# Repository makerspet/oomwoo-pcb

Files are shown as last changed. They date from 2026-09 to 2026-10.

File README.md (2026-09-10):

<div align="center">

# OOMWOO I/O Board

*Open-source robot vacuum you build yourself.*

Raspberry Pi CM4/CM5 socket · STM32G473 MCU · Motor drivers · Sensors · 2x MIPI cameras · 4S charging · KiCad





</div>

Part of [OOMWOO open-source robot vacuum](https://github.com/makerspet/oomwoo) project.

oomwoo_main_pcb_placement

Get [MCU firmware](https://github.com/makerspet/oomwoo-io-firmware/).

## Architecture notes

Consumer vacuums typically split compute into CPU and MCU. The MCU ([real examples](https://robotinfo.dev/)) controls
- all motors - driving wheels, suction fan, side brushes, mop motors, mop lift servos, pump and so on
- all sensors except below - IR cliff, IR side proximity, IR docking, wheel drop, bumper (IR or micro-switches), motor encoders, ultrasonic carpet sensor
- all push buttons
- 2D LiDAR motor RPM
- power - battery charging, motors power on/off
- all safety sensors - overcurrent for all motors (cheap vacuums ignore overcurrent sensing)

I/O board also provides audio encoders/decoders, amp, speaker (connector), mics (if any).

CPU receives
- 2D LiDAR data over serial port
- IMU (sometimes IMU gets forwarded via MCU) over SPI/I2C
- cameras (2x MIPI for visual obstacle avoidance)

MCU (and CPU) are usually always active. This allows the user to start cleaning at any time (especially via app remotely). Exceptions:
- no power (battery dead and no dock power)
- user explicitly shut down the vacuum by long-pressing the power button

The MCU's overarching constraint is to ensure robot safety. This is necessary to pass CE mark tests. Here is how MCU ensures safety:
- MCU firmware uses FreeRTOS or similar, static memory allocation, watchdog, guaranteed reaction time
- MCU acts as watchdog for CPU, resets CPU if CPU becomes unresponsive
- MCU connects to CPU over serial using a custom serial protocol ([concrete example](https://github.com/codetiger/VacuumRobot)). No micro-ROS to reduce dependencies, prevent bugs from updated 3rd party libraries slipping into safety-critical MCU firmware.
- MCU shuts down some (or all) motors when MCU detects overcurrent (brush stuck)
- MCU shuts down all motors (including power to all motors) when CPU becomes unresponsive (to prevent CPU sending garbage commands to MCU)
- MCU monitors battery charging, shuts it down when needed (battery too hot)
- MCU stops driving wheel motors when bumper sensors activate
- MCU tests motors, sensors
- MCU does not depend on CPU
- MCU toggles watchdog GPIO; otherwise an external-to-MCU circuit shuts down motor power

Consumer vacuums place CPU and MCU on the same PCB board. Since OOMWOO has to be hackable, it seems best to separate I/O from the compute. Therefore, this I/O board needs to have
- MCU and programming header
  - likely STM32G070RBT6 because it has 56 GPIOs, 16 ADC channels, costs $1 at JLCPCB, has LQFP package for easy PCBA - a rare combination
  - see tentative [I/O board spec](https://github.com/makerspet/oomwoo-io-board/blob/main/docs/SPEC.md)
- all vacuum motor drivers (with connectors), driven by the MCU
  - cliff, side proximity, docking, bumper, carpet, water tank full/empty, dust bin present, motor overcurrent, motor encoders
- MCU connected to all sensors (except those handled by CPU like LiDAR serial, MIPI cameras I/O, IMU); sensor connectors
- control circuit for 2D LiDAR's motor (controlled by MCU)
- battery charging, power management (motors power on/off, charging on/off, power shut down), power for CPU compute module (see below)
- push buttons (home, power, etc.) and UI LEDs
- dock connector (dock power, sense dock present)
- USB power for charging; USB for serial shell, etc.
- audio encoder/decoder, audio amp, mics (if any)
- SD card for hacking, cheap large storage
- connect IMU FSYNC to MCU to synchronize MCU timestamps with IMU data streaming to CPU

Consumer vacuums usually don't have a CPU fan/heatsink because the vacuum's suction fan can (indirectly) cool the CPU/MCU PCB. Therefore, no CPU fan on this I/O board.

As far as compute - currently it seems best to use a Raspberry Pi CM4/CM5 compute module. Why?
- CM4/CM5 modules cost a bit less than a full Raspberry Pi 4/5
- CM4/CM5 have lower profile/height vs a full Raspberry Pi 4/5, important to keep vacuum cleaner slim
- there are plenty of 3rd party compute modules pin-compatible with CM4/CM5, making the compute swappable, hackable
  - 3rd party compute modules with NPUs are especially interesting because we need NPU for real-time camera-based obstacle detection

Compute module headers should expose
- 2x MIPI camera I/O
- 1x serial for CPU-MCU comms
- 1x serial for CPU-LiDAR comms
- 1x SPI (or I2C) for CPU-IMU comms
- audio (digital?) I/O
- power from I/O board to CM
- a few TBD GPIOs
  - MCU GPIO to reset CPU

This board should be designed using an open-source PCB tool (KiCad seems like a good choice).

## License

[Apache License 2.0](LICENSE).

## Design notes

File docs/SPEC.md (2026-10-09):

# OOMWOO I/O Board spec (work in progress)

See [vacuum BOM](https://github.com/makerspet/oomwoo/blob/main/BOM.md) for details.

## Reverse engineering data

Drive, brush and fan motors draw power directly from the 4S battery (not via a DC-DC converter). The battery is 4*3.6V=14.4V nominal, 4*2.9V=11.6V discharged and 4*4.2V=16.8V fully charged.

### DC Motors

<table>
  <tr><th>Part</th><th>Voltage</th><th>No load</th><th>Stall</th><th>Notes</th></tr>

  <tr>
    <td rowspan="3">Drive wheel</td><td>16.8V</td><td>0.12A</td><td>2A</td>
    <td rowspan="3">JST ZH 1.5mm 7-pin housing; RS-360-SH-15250 motor;
      pin 1 MOT+, 2 MOT-, 3 Hall GND (brown), 4 Hall signal out (blue, open collector), 5 Hall VCC (3.3-5V, orange), 6 COM wheel drop switch, 7 ON wheel drop switch;
      fits Roborock S4 Max, S45 Max, S5 Max, S50 Max, S55 Max, S6 MaxV, S6 Pure, S65 Pure, S65 MaxV, S7, S7 Pro, S7 MaxV, S7 Max Ultra, S70, S75, E4, E45, E5, E50, E55, G10, T7, T7S, Q5, Q7, Q7 Max, and Q Revo;
      purchased <a href="https://www.aliexpress.us/item/3256811615892849.html">here</a>; power supply current limit headroom ~1A;
      the wheel assembly appears to be identical to <a href="https://github.com/makerspet/oomwoo/tree/main/contributions/part-specs/IKsares/drive-wheel">this one</a> available
      <a href="https://www.aliexpress.us/item/3256807172774304.html">here</a> that uses GM-RS360-16248 motor with stall current possibly reaching ~3A.
    </td>
  </tr>
  <tr><td>14.4V</td><td>0.12A</td><td>1.7A</td></tr>
  <tr><td>12V</td><td></td><td></td></tr>

  <tr>
    <td rowspan="3">Main brush</td><td></td><td></td><td></td>
    <td rowspan="3">Roborock S50 S51 S55 XIAOWA C10</td>
  </tr>
  <tr><td>16.8V</td><td>0.27A</td><td>7A</td></tr>
  <tr><td></td><td></td><td></td></tr>

  <tr>
    <td rowspan="3">Side brush FlexiArm</td><td></td><td></td><td></td>
    <td rowspan="3">RC500-KW/14440/DV motor; JST ZH 1.25mm 5-pin housing, 14.4V motor nominal;
      pin 1 MOT-, 2 MOT+, 3 IR output? (Arm folded in fully -> sensor blocked), 4 IR GND? 5 IR VDD?
      fits Roborock Qrevo Master, Qrevo Slim, S8 Max V Ultra</td>
  </tr>
  <tr><td>16.8V</td><td>0.07A</td><td>1.7A</td></tr>
  <tr><td></td><td></td><td></td></tr>

  <tr>
    <td rowspan="3">Side brush fixed</td><td></td><td></td><td></td>
    <td rowspan="3">RC500-KW/14440/DV motor; fits Roborock Robot Vacuum S50 S51 S52 S55 S502-00/01/02/03** S552-00 S60 S61 S65 S5 Max S6 Pure MAX S7 S70 S75</td>
  </tr>
  <tr><td>16.8V</td><td>0.07A</td><td>1.7A</td></tr>
  <tr><td></td><td></td><td></td></tr>

  <tr>
    <td rowspan="3">Mop rotary fixed</td><td>16.8V</td><td>0.15A</td><td>5.3A</td>
    <td rowspan="3">JST PH 2.0 4-pin housing, RS-385PH-2466 motor; pin 1 VCC fixed, 2 GND fixed, 3 GND FlexiArm, 4 VCC FlexiArm;
    fits Roborock Qrevo Master, Qrevo Slim, S8 Max V Ultra, G20S, V20, P10S Pro</td>
  </tr>
  <tr><td>14.4V</td><td>0.16A</td><td>4.3A</td></tr>
  <tr><td>11.6V</td><td>0.15A</td><td>3.7A</td></tr>

  <tr>
    <td rowspan="3">Mop rotary FlexiArm</td><td>16.8V</td><td>0.2A</td><td>5A</td>
    <td rowspan="3">JST PH 2.0 4-pin housing, RS-385PH-2466 motor; pin 1 VCC fixed, 2 GND fixed, 3 GND FlexiArm, 4 VCC FlexiArm;
    arm actuator likely JST GH 1.25; pin 1 black (ground?), 2 red (power?);
    fits Roborock Qrevo Master, Qrevo Slim, S8 Max V Ultra, G20S, V20, P10S Pro</td>
  </tr>
  <tr><td>14.4V</td><td>0.17A</td><td>4.3A</td></tr>
  <tr><td>11.6V</td><td>0.16A</td><td>3.6A</td></tr>

  <tr>
    <td>Water mini-pump</td><td>5V</td><td>55mA</td><td></td>
    <td><a href="https://www.tcstec.com">TCS Precision Technology<a>JSB1523025 peristaltic, 5V nominal (loud); JST ZH 2-pin housing; pin 1 MOT+, 2 MOT-</td>
  </tr>

  <tr>
    <td>Water mini-pump</td><td>5V</td><td>60mA</td><td></td>
    <td><a href="https://www.dyxminipump.com">ShenZhen Deyuxin Technology</a>DSB030-C peristaltic, 5V nominal (quiet); JST PH 2.0 2-pin housing; pin 1 MOT+, 2 MOT-</td>
  </tr>

  <tr>
    <td>Water mini-pump</td><td>5V</td><td>87mA</td><td></td>
    <td><a href="https://www.dgjbf.com">Dongguan Jingbofang Precision Electronics<a>JSB030-5A peristaltic, 5V nominal (loud); no connector</td>
  </tr>

  <tr>
    <td>Water mini-pump</td><td>5V</td><td>110mA</td><td></td>
    <td><a href="www.yyjiayin.com">Jiayin</a> JYPDM-6B peristaltic, 5V nominal (quiet-ish); JST XH 2.54mm 2-pin; pin 1 MOT+, 2 MOT-</td>
  </tr>

  <tr>
    <td>Water mini-pump</td><td>5V</td><td>330mA</td><td></td>
    <td><a href="https://conjoinfluid.com/">Conjoin</a> CJWP12-AA05A peristaltic, 5V nominal (loud); likely JST GH 1.25mm housing; pin 1 blue (ground?), 2 red (power?)</td>
  </tr>

</table>

### BLDC Motors

<table>
  <tr><th>Part</th><th>Voltage</th><th>Unobstructed</th><th>Fully Obstructed</th><th>Notes</th></tr>

  <tr>
    <td rowspan="3">Fan MSD-G v1</td><td>16.8V</td><td>3.65A</td><td>6A</td>
    <td rowspan="3">LHE MX3.0 4-pin (2x2) 3.0mm with latch header (aka Molex Micro-Fit 3.0); pin 1 VCC, 2 GND, 3 FG (open collector), 4 PWM (low off);
    fits Dreame X50 Ultra (20 kPa), X50 Master (20kPa)</td>
  </tr>
  <tr><td>14.4V</td><td>4.2A</td><td></td></tr>
  <tr><td>12V</td><td>5.25A</td><td></td></tr>

  <tr>
    <td rowspan="3">Fan BL27302101</td><td>16.8V</td><td>1.8A</td><td>1.8A</td>
    <td rowspan="3">JST PA 2mm 6-pin shrouded header; pin 1 VCC, 2 VCC, 3 GND, 4 GND, 5 PWM (low off), 6 FG (open collector);
    fits Roborock Saros 20 (36 kPa); </td>
  </tr>
  <tr><td>14.4V</td><td>2.1A</td><td></td></tr>
  <tr><td>12V</td><td>2.5A</td><td></td></tr>

  <tr>
    <td rowspan="3">Fan BL24131616<sup>*</sup></td><td>16.8V</td><td>1.75A</td><td>1.75A</td>
    <td rowspan="3">JST PA 2mm 5-pin shrouded header; pin 1 ID (22k to GND), 2 FG (open collector), 3 PWM (low off), 4 GND, 5 VCC;
    fits Roborock G20S P10 Pro (7 kPa), P10s Pro (11 kPa), P20, G20S S8 MaxV (10 kPa), Xiaomi S40 OV81 (10 kPa)</td>
  </tr>
  <tr><td>14.4V</td><td>2.1A</td><td>2.1A</td></tr>
  <tr><td>12V</td><td>2.6A</td><td>2.6A</td></tr>

  <tr>
    <td rowspan="3">Fan 22N704V160<sup>*</sup></td><td>16.8V</td><td>1.75A</td><td>3.25A</td>
    <td rowspan="3">JST PA 2mm 5-pin shrouded header; pin 1 ID (5 Ohm to GND), 2 FG (open collector), 3 PWM (low off), 4 GND, 5 VCC;
    fits Roborock G20S P10 Pro (7 kPa), P10s Pro (11 kPa), P20, G20S S8 MaxV (10 kPa), Xiaomi S40 OV81 (10 kPa)</td>
  </tr>
  <tr><td>14.4V</td><td>2.05A</td><td>2.7A</td></tr>
  <tr><td>12V</td><td>2.5A</td><td>2A</td></tr>

  <tr>
    <td rowspan="3">Fan 20N704R990F aka 20N704R980</td><td></td><td></td><td></td>
    <td rowspan="3">JST PH 2.0mm 4-pin shrouded header; pin 1 FG (open collector), 2 PWM (low off), 3 GND, 4 VCC; 20N <a href="https://www.nidec.com/en/product/search/category/B101/M102/S100/NCJ-20N-Type-4/">motor spec</a>
      ~5.1-6 kPa, fits Roborock S7 (2.5 kPa), S7 Pro (5.1 kPa), S7 MaxV (5.1 kPa), S75 MaxV (5.1 kPa), S8 (6 kPa), S8 Plus (6 kPa), S8 Pro Ultra (6 kPa), S8 MaxV Ultra (8 kPa), G20 (6 kPa), Q7 Max (4.2 kPa), Q7 Max Plus (4.2 kPa)</td>
  </tr>
  <tr><td></td><td></td><td></td></tr>
  <tr><td></td><td></td><td></td></tr>

  <tr>
    <td rowspan="3">Fan MSD-C-3</td><td></td><td></td><td></td>
    <td rowspan="3">JST PH 2.0mm 4-pin shrouded header; pin 1 FG (open collector), 2 PWM (low off), 3 GND, 4 VCC;
      fits Dreame L10s Prime (4 kPa), L10s Prime Ultra (5.3 kPa v1), L10s Prime Pro, D10s Plus (5 kPa), X10+ (4 kPa), X20+ (6 kPa)</td>
  </tr>
  <tr><td></td><td></td><td></td></tr>
  <tr><td></td><td></td><td></td></tr>

  <tr>
    <td rowspan="3">Fan MSD-D</td><td></td><td></td><td></td>
    <td rowspan="3">JST PH 2.0mm 4-pin shrouded header; pin 1 FG (open collector), 2 PWM (low off), 3 GND, 4 VCC;
      fits Dreame L20 (7 kPa), L30 Ultra (7.3 kPa), S10 (5.3 kPa), S10 Plus (7 kPa)</td>
  </tr>
  <tr><td></td><td></td><td></td></tr>
  <tr><td></td><td></td><td></td></tr>

  <tr>
    <td rowspan="3">Fan 20N709U020</td><td></td><td></td><td></td>
    <td rowspan="3">JST PH 2.0mm 4-pin shrouded header; pin 1 FG (open collector), 2 PWM (low off), 3 GND, 4 VCC;
      fits Dreame L10s Ultra (5.3 kPa), L10s Pro (5.3 kPa), L10 Ultra (5.3 kPa), D10s Pro (5 kPa); Xiaomi X20+ (6 kPa), C102 B101CN, X10+ (4 kPa), S10 Plus (4 kPa)
    </td>
  </tr>
  <tr><td></td><td></td><td></td></tr>
  <tr><td></td><td></td><td></td></tr>

  <tr>
    <td rowspan="3">Fan BL24131607</td><td></td><td></td><td></td>
    <td rowspan="3">JST PH 2.0mm 5-pin shrouded header; pin 1 ID (20k to GND), 2 FG (open collector), 3 PWM (low off), 4 GND, 5 VCC;
      fits Roborock P10 Pro (7 kPa), Qrevo Maxv (7 kPa), P10S (7 kPa), Qrevo S (7 kPa), Qrevo Pro (7 kPa)</td>
  </tr>
  <tr><td>15V</td><td>1.7A</td><td>2.7A</td></tr>
  <tr><td></td><td></td><td></td></tr>

</table>

### Sensors, Battery

<table>
  <tr><th>Part</th><th>Voltage</th><th>Notes</th></tr>

  <tr>
    <td>Cliff sensors</td><td></td>
    <td>JST PHDR-16VS 2.0mm 8x2 housing, mates JST S16B-PHDSS, JST B16B-PADSS; fits iRobot Roomba 500 600 700 800 528 552 564 595 560 570 610 615 620 625 630 650</td>
  </tr>

  <tr>
    <td>Battery</td><td></td>
    <td>4S2P 14.4V nominal <a href="https://images.thdstatic.com/catalog/pdfImages/55/55d2f7f6-2ed9-44ed-ab4e-fb20d231c897.pdf">BRR-2P4S-5200FL battery</a> or similar;
    4-pin 3mm pitch with latch male LHE MX3.0 (C3001-H04), Molex Micro-Fit 3.0;
    pin 4 BAT+, 3 NTC (10.7K), 2 ID (0.62M to ground), 1 GND</td>
  </tr>

  <tr>
    <td>Carpet sensor</td><td>14.4V (VUS boost rail)</td>
    <td>290KHz piezo ultrasonic, <a href="https://htwsensor.en.made-in-china.com/product/HfMYgjwoZxVh/China-300kHz-Carpet-Material-Recognition-Sensor-for-Robotic-Vacuum-Cleaner-Ultraosinc-Sensor.html">likely this one</a>,
      JST ZH 2-pin housing; <a href="https://makerspet.com/blog/how-to-source-bom-for-oomwoo-open-source-vacuum-robot/#carpet-sensor">sourcing notes</a>
      pin 1 white, 2 black (driven by AC, polarity doesn't matter?)
    </td>
  </tr>

</table>

All components tested with Agilent 6653A unless mentioned otherwise. The current limit was set high enough to not be triggered.

<sup>*</sup> Appear to be interchangeable

Mop lift TBD

Mop arm actuator - Roborock FlexiArm; later replace with own design

## Compute + Camera

- Camera (changed Oct 2026): the camera moves off the Compute Module to the STM32 - one parallel-interface (DVP) RGB module, so it also works when an old smartphone is the compute. See [Front sensors module board](#front-sensors-module-board). **Open:** keep the 15-pin MIPI connectors as a Pi-only option, or drop them? The schematic's MIPI-CAMERA sheet predates this change.
- internal USB 2.0 header (JST GH 4-pin, 0.5 A polyfuse, USBLC6 ESD) for the optional mic-array board or `rpiboot`; see [USB, UART allocation](#usb-uart-allocation)
- M.2 slot provisioned, PCIe lane routed, with its own 3.3 V buck (VCC3V3_M2, enabled by the CM via PCIE_PWR_EN) - to experiment with NPU accelerator(s) like Hailo
- SD card slot, powered through an RT9742 load switch (SD_PWR_ON)

Undecided TODO 
- USB-C 3.0+, CM5 only - to experiment with accelerator(s) like Coral TPU
- Keep the compute socket able to take an integrated-NPU module too (Radxa CM5) or premium-upgradeable (CM5 + M.2 Hailo).
- Flag it to the PCB contractor as a design item: M.2 E-key (WiFi) + an M.2 M-key/PCIe (NPU or NVMe), PCIe lane routing, and the thermal path for a few-watt accelerator in a suction-cooled enclosure

### Robot

Current schematic (2026-09):
- charging input is 24 V DC, from the dock contacts (CONTACT_CHGR) or a DC-005 barrel jack, into an SLM6900 buck charger configured for 4S (about 2.2-2.6 A). The battery NTC goes straight to the charger, so over-temperature cut-off is in hardware
- the system rails run from the battery (BAT-VCC), not from a power-path SYS rail
- USB-C is a 5 V *output* for the phone-as-compute option (AP64501 buck enabled by PWR_EN, through a TMI6240 current-limited switch), with D+/D- to the STM32 USB (PA11/PA12). **TODO:** CC1/CC2 are unconnected; a phone on a C-to-C cable will neither charge nor enumerate until CC is configured (Rp to charge, Rd for the phone-as-host data mode)
- the USB-C PD input and power-path charger below are the original plan, not in the current schematic

Original plan:
- the robot has 2 power inputs: USB-C and dock
  - robot receives 20-24V fixed DC from the dock
  - USB-C power use PD, request 20-24 V minimum (to step it down to 4S battery)
  - optional PPS
  - if a low-power USB-C 5V, 9V or 15V brick source is attached (no 20V/PPS), either charge slowly (optional) through a boost path or cleanly refuse and signal "insufficient charger" rather than misbehaving
- robot requires 65W minimum input (from the dock) with system power-path charger (a charger IC with a SYS rail)
  - support the vacuum charging and Raspberry Pi running simultaneously
  - assume Raspberry Pi is always on (to handle user access over Wi-Fi at any time)
  - Pi CM5 worst case ~15.6W
  - M.2
  - Healthy charge ~40 W (~0.5C into the 75 Wh pack)
  - ~65–70 W total
- cap charge at ~0.5C regardless of charging adapter power
- MCU reset drops everything to a safe state, so motors are off during reset, firmware upload and firmware crash
  - watchdog: see [Safety and power rails](#safety-and-power-rails)

### Dock

- the dock is powered from an external certified 24/25.2 V DC brick (~200–350 W)
  - use external brick for safety, the dock enclosure only ever sees 24 V DC
  - reuse a 25.2 V stick-vac motor for auto-empty, e.g. Dreame M10-E-4 25.2 V/310 W
- the dock has only 2 contacts: DOCK+ and GND
  - dock contacts feed a fixed 24V+ DC
  - the dock detects load/robot presence, energizes DOCK+ only when robot is detected (reliably, after a couple of seconds)
  - dock contacts are spring loaded, gold-coated pogo pins ≥4 A, placed rear-vertical, above water line
- ambient fan(s) for mop drying
  - no hot mop dry for now
- 2x water pumps: clean-feed + dirty-evacuate
  - diaphragm, 12–24 V
- dock PCB
  - ESP32 (WiFi + BLE + control)
  - Pump/fan drivers (brushed DC)
  - IR beacon LEDs + driver
  - robot/load presence-detect + charging contact energize FET
  - Level sensors (float/capacitive) clean-low, dirty-full
  - high-side FET for auto-empty blower
  - fuse, DC inlet, TVS
  - buck DC-DC 24V to 5V, 3.3V for ESP32, sensors

### IR receiver ICs

- required to 1) find dock without map (beacon), 2) communicate with the dock (bi-directional, ~1 kbit/s)
  - Maybe we'll use LiDAR for docking (simpler mechanical, PCB design). If that fails, 3) docking.
- use 38 kHz NEC protocol receivers (56 kHz parts are Vishay-only, expensive, barely stocked)
  - firmware: time-share IR transmissions
  - dock stops 
- TSOP38238 costs ~$0.56, relatively expensive; economical IC options, sorted by preference
  - Everlight IRM-H638T/TR2	C91447 SMD 5×4 $0.168 194k Deep stock, reputable.
  - Everlight IRM-3638T	C42421366 Through-hole $0.103 206k Side-looking, cheapest reputable through-hole; [datasheet](https://www.alldatasheet.com/datasheet-pdf/view/229626/EVERLIGHT/IRM-3638T.html).
  - Yongyu GRM-4033H4C6-ET2	C51901765	SMD	$0.118	2.7k	50 µA, 2.4–5.5 V. Best SMD challenger.
  - TONYU DY-IRM383T/LP-T-20	C46682928	Through-hole	$0.068	420	100 µA, 2.7–5.5 V. Cheapest real receiver, sunlight rejection not specified; [datasheet](https://file.aichiplink.com/static/lcsc/documents/2026-01-29/18c143340b0d5fc0ffdf5ff7098aaff5.pdf).
  - TONYU DY-IRMA385-T5-W1-F1	C7433009	SMD-3P	$0.110	2.1k	200 µA, ±35°. Narrower field of view.
  - Chau Light ZSIRM-Z1QN86	C5337492	SMD 5×4.2	$0.112	1.8k	400 µA, 45°.
  - TONYU DY-IRMA386/387	C6075467/68	Through-hole	$0.128	124/660	±60° wide field of view, low stock.
  - XINGLIGHT XL-IRM0038C-38X	C42400831	SMD 5×4.2	$0.133	137	150 µA, 75°, –40 °C to +85 °C. Stock too thin.
- Deciding factors - stock depth, sunlight rejection, SMD (cheaper to assemble), angle of view (wide for dock search, narrow for docking, comms), side-looking vs straight up orientation
  - current draw battery drain is not a factor

### Power path

Standard capability of power-path charger ICs - TI bq25 family and similar.

```
USB-C 20V ─► [PD sink] ─► [power-path charger] ─┬─► SYS rail ─► 14.4→5V buck ─► Pi (always-on)
                                                └─► charges 4S pack
Battery ────────────────────────────────────────┘ (supplements SYS if input insufficient)
```

- Docked: the Pi runs from the input via SYS; the battery charges from the surplus; once full, charge current → 0 and the Pi keeps running off input — no needless battery cycling while docked (also a longevity win).
- Undocked: SYS seamlessly falls back to the battery — the Pi never browns out during the handoff. This is exactly what makes "pause → return to charge → resume" and "app connects anytime" work cleanly.
- Input-limited: if only a weak brick is attached, the battery supplements SYS so the Pi stays up, and charge current backs off. Graceful degradation for free.

Details

1. 65 W = 20 V / 3.25 A → e-marked cable required. Above 3 A / 60 W, USB-C needs a 5 A e-marked cable. Unavoidable at 65 W (20 V is PD's max fixed voltage) — just document it. 65 W bricks ship with an e-marked cable anyway.
2. Dynamic power management (VIN/IIN-DPM): the charger must throttle charge current to keep total draw within the negotiated PD budget, prioritizing the Pi/SYS load. Standard on power-path chargers.
3. Cap charge current at ~0.5C (~2.6 A into the pack) for cell life, regardless of surplus — don't let a big brick fast-charge the cells.
4. Two DC inputs, one charger: the robot's own USB-C port and the dock contacts both present ~20 V DC → OR them into the charger's VBUS with priority/ideal-diode selection (both are the same voltage, so it's clean).
5. Dock side: dock has its own PD sink + 65 W brick, passes ~20 V to the contacts. At 20 V, 65 W ≈ 3.25 A over the contacts → size the pogo/spring contacts for ~4 A with margin.

Net spec

1. USB-C PD, 65 W minimum (20 V / 3.25 A), on both the robot port and the dock (each with its own PD sink); e-marked cable expected.
2. Power-path 4S charger with a SYS rail feeding the Pi's 5 V buck, so the Pi is always-on from input when docked and from battery when not, with seamless handoff and battery-supplement under load.
3. DPM + 0.5C charge-current cap; OR the two DC inputs into one VBUS; dock contacts rated ~4 A.

## How to drive carpet sensor

- 290KHz ultrasonic piezoelectric analog
- 14.4 V DC stabilized (VUS, MT3608 boost from 5 V; not the 4S battery directly)
  - DC voltage set by the MT3608 feedback divider: VUS = 0.6 V x (1 + R160/R159) = 0.6 x (1 + 232k/10k) ≈ 14.5 V
  - current consumption - calculate 300KHz driving 1300±20% pF per sensor spec
  - make it withstand shorts
- connect sensor analog I/O to MCU ADC input
- use STM32G473VCT6 internal op-amp as echo input (AC via a cap)
- clamp amplitude to 3.3V (back-to-back clamp diodes)
- add a series resistor to STM32 op-amp input (extra protection against 12V)
- (firmware) bias the MCU internal op-amp to Vref/2 using MCU internal DAC
- (firmware) configure ADC pre-amp gain, PGA mode (op-amp bandwidth is 10MHz)
- (firmware) configure op-amp to output signal to internal ADC channel
- drive sensor analog I/O with one low-side N-FET (Q18, AO3400) and a 330 Ω 1206 pull-up (R7011) from VUS, AC-coupled to the piezo through C18
  - the earlier P/N half-bridge was dropped: its high side turned off through a 100k pull-up, far too slow at 290 kHz, so both FETs would conduct every cycle (shoot-through)
  - one GPIO (LO) drives the gate through R60 (10 Ω); R7012 (100k) pulls the gate low so the FET is off while the MCU is in reset or being flashed
  - the freed HI GPIO now enables the motor rail (~VM-VBAT-EN)
- (firmware) drive the sensor in short bursts only: LO held high puts ~0.63 W into R7011
- (firmware) release LO (low), then measure using ADC, calculate return amplitude
- TODO get the sensor vendor's reference driver circuit to confirm drive voltage and pull-up value

## LiDAR pinouts

On the main board (current schematic):
- LIDAR1: JST GH 1.25 mm socket for the LDROBOT LD14P; MOTOR-CTRL through a 1k series resistor (R7008) so a hung MCU can't back-power an unpowered LiDAR
- LIDAR2: 0.1" 1x4 male pin header (XFCN PZ254V-11-04P) for other 2D LiDARs via jumper wires: 1 LiDAR RX, 2 GND, 3 MOT- (low-side switched by Q20), 4 VM-5V-LIDAR
- both are powered from VM-5V-LIDAR, which cuts the whole LiDAR (laser included), not just its motor; see [Safety and power rails](#safety-and-power-rails)

```
X-WPFTB-V2.6.2 PCB marking - JST GH 1.25mm 4-pin shrouded housing

D-WPFTBCD-V1.0.1 PCB marking - JST GH 1.25mm 4-pin shrouded housing

LDROBOT LD14P lookalike - JST GH 1.25mm 4-pin shrouded housing

Mystery mini - JST GH 1.25mm 5-pin shrouded housing
```

## Front sensors module board

- 2x VL53L7CH (or VL53L7CX), 90° diagonal = ~63° horizontal FoV each
  - each turned ~30° left, right to cover ~126° horizontal FoV
  - obstacle *detection*
- 1x RGB camera, parallel (DVP) interface, wide-angle, pitched down (changed Oct 2026 from
  2x OV5647 NIR stereo with structured illumination)
  - images the floor - dirty or clean, and cleaning results - and obstacles ahead, up to about
    the robot's height (privacy)
  - obstacle *recognition*; colour helps, and RGB modules are cheaper with more lens choice than NIR
  - non-MIPI and low bandwidth, read by the STM32, so it works with both a Pi CM and an old
    smartphone over USB CDC; this rules out full ToF cameras, stereo depth and structured light
  - **Open question:** the STM32G473 has **no DCMI** (camera interface) peripheral. Options:
    GPIO capture with timer-triggered DMA at low resolution; a module with its own SPI/FIFO
    buffer (ArduCAM-style); or a small bridge MCU with a camera interface
  - **Tentative:** a Raspberry Pi Pico-class MCU (RP2040, or RP2350) as the camera bridge. Its PIO
    blocks capture a DVP camera well (community OV7670/OV2640 examples exist); frames then go to
    the STM32 over SPI or UART
    - RP2040/RP2350 are QFN only, against the hand-solderable preference. A castellated module
      (Pico-style, or a smaller RP2040 board) keeps it hand-solderable and brings its own flash and
      crystal
    - bandwidth: the STM32's USB FS (12 Mbit/s) to a phone carries raw QVGA RGB565 (150 kB a
      frame) at only a few fps; a camera with hardware JPEG (e.g. OV2640) or a lower resolution
      eases this
- white torchlight LEDs for the camera (was NIR illumination with a projection pattern); many
  consumer robots use white, e.g. Dreame L60 Ultra PE and Roomba j7
- breaks into multiple PCBs using holes
  - central - 2x TSOP38238 (separated by a baffle) for dock homing
  - left - VL53L7CH pointed 30° left
  - right - VL53L7CH pointed 30° right
  - RGB camera with white torchlight LEDs

## Side sensors module board

- TSOP38238 for dock detection
- consumer vacuums use analog Sharp short-range distance sensor
  - use VL6180V1NR/1 C2655167 $1.03 100pcs 18° FoV diagonal? Obsolete, similar to VL53L4CD
  - use VL53L0CX GY-530, TMF8806 or similar instead? Dust may be an issue.
  - VL53L0CXV0DH/1 C91199 $2.11 100pcs
  - VL53L4CDV0DH/1 C3178291 $2.19 100pcs

## Sensors

- VL53L7CH
  - Arduino library https://github.com/stm32duino/VL53L7CH
  - hookup schematic https://eu.mouser.com/en/new/stmicroelectronics/stm-vl53l7ch-tof-sensor
  - LPn pin sets I2C address

## Water pump

- 5V DC motor, peristaltic; ~0.6A rated, 1A max
- powered from VCC-5V-REG through Q8 (AO3401 high-side switch) as rail VM-5V-WATER-PUMP; on only while WD_OK is high AND WATER-PUMPU-CTRL is low (Q7004)
- the pump-side voltage is read by the STM32 ADC (WATER-PUMP-SENSE-ADC divider R81/R47)
- supply is fixed at 5 V (the old "settable by resistors" idea isn't in the schematic)

## GPIO

Please see the [PCB schematic](https://github.com/makerspet/oomwoo-io-board/tree/main/kicad/PDF) for up-to-date GPIO list.

TODO before layout/fabrication: confirm whether GPIO entries 36 and 46 are intentionally separate bumper inputs or a duplicate label.

Carpet sensor notes (see [How to drive carpet sensor](#how-to-drive-carpet-sensor) for the driver)
- calibrate return amplitude when docked
- 2-pin connector "1.25mm Y" per spec, exact model unclear
  - not Molex PicoBlade 1.25mm, not JST GH 1.25mm

## Audio IC

I2S DAC MAX98357AETE_T C910544 TQFP is expensive at $0.88 100pcs, has a built-in speaker driver.
NS4168 C910588 $0.47 is a MAX98357AETE_T clone, 7K+ stock, except in a different package (ESOP).
That happens to be advantageous because ESOP is better than TQFP for bring-up and DIY hacking.

Claude says:
- NS4168 works the same way as the MAX98357A: I²S in, mono class-D out, driving the speaker directly.
- Specs: 3.0–5.5 V supply, 2.5 W into 4 Ω at 5 V, 8–96 kHz sample rates. It has a CTRL pin that picks the left or right channel and also acts as shutdown.
- No MCLK needed. This matters because the Pi's I²S port can't output an MCLK; the MAX98357A was chosen for the same reason.
- Linux: like the MAX98357A, it has no control interface. The existing Raspberry Pi `max98357a` overlay drives any chip like this, so the software stays the same on CM4 and CM5.
- Check the CTRL-pin voltage levels against the datasheet and strap it for the left channel or the (L+R)/2 mix; either is fine for mono voice prompts.
- Power: run the amp from the 5 V rail, with 10–22 µF bulk plus 100 nF right at the power pin. Peak current into a 4 Ω, 2–3 W speaker is under 1 A.
- EMI: the outputs switch at high frequency with no filter. Keep speaker traces short, or twisted if they go through wires, and away from the IR receivers and the LiDAR data lines. Leave pads for ferrite beads on the speaker leads in case the sim or bench test shows interference.
- Shutdown: wire the CTRL pin to a GPIO so you can power the amp down when idle. That saves the ~13 mA quiescent current and avoids pops at boot.
- Pins: CM4 and CM5 both use GPIO18 (BCLK), GPIO19 (LRCK) and GPIO21 (DOUT). I²S is the one audio path both modules share. PWM audio on GPIO12/13 is cheaper on CM4, but I believe the CM5 doesn't support it, so it doesn't suit a carrier for both.

## Mic array (optional)

Claude: build it as a USB mic board. Four digital PDM MEMS mics sampled by an RP2040, which shows up as a standard 4-channel USB microphone. It needs no Pi-specific driver and costs roughly $2–3 in parts. It works the same on CM4 and CM5.

Why not wire the mics to the Pi's I²S bus?
- Not enough inputs. The CM4 has one I²S data-in pin (GPIO20). One data line carries two mics (left and right), so plain I²S tops out at 2 mics. Getting 4 means TDM-output mics, which are expensive and rare, plus fiddly TDM setup in the Linux device tree. The CM5's audio block is different again.
- Shared with the speaker. The NS4168 already uses that I²S bus's clock lines. The mics would be forced to run at the speaker's sample rate, and the mic board would inherit any CM4/CM5 differences.
- Fast clock over a cable. A ~3 MHz bit clock has to run up a flying cable to the top of the LiDAR cage, right beside the LiDAR motor.

The one real advantage of I²S is that mic and speaker share a clock, which makes echo cancellation easier. See the trade-off near the end.

Why USB with an RP2040
- Works on any compute. It looks like an ordinary USB microphone, so it works on CM4, CM5, a laptop on the bench, and possibly a phone over USB OTG.
- All four mics are sampled together. Pairs of PDM mics share a data line: one mic outputs on the rising clock edge and the other on the falling edge. So 4 mics need 1 clock line and 2 data lines, all on the same clock. That exact sample alignment is what direction-finding needs, and USB can't disturb it.
- Converting PDM to audio: the RP2040's programmable I/O captures the raw bit streams and firmware filters them down to 16 kHz audio. Four channels at 16 kHz should fit on its two cores; confirm on the first board. The pin-compatible RP2350 has more headroom if it's tight. There is existing open-source code for Pico PDM mics and for TinyUSB USB-audio to start from.
- Simple cable: 4 wires (5 V, D+, D−, GND) up to the cage.
- Easy for people to hack: the RP2040 is well known, and there are free pins for LEDs or a button.

Mic geometry
- Use 4 mics, not 3. Three is enough to find a direction on the floor plane, but 4 in a square gives better beamforming, spare measurements and simpler maths.
- Make the array as wide as the cage top allows, about 60–70 mm diameter, similar in size to ReSpeaker-type arrays. Wider spacing gives better direction accuracy.
- At 65 mm across, sound takes at most 0.19 ms to cross the array: only about 3 samples at 16 kHz.
- Frequency-domain methods such as SRP-PHAT (used by the ODAS direction-finding library) handle fractions of a sample. Capture at 48 kHz if you want finer resolution.
- Mount the mics on the underside of the board. Use bottom-port mics with the sound hole drilled through to the top. The top stays flat and the mics are protected.
- Cover each port with an acoustic mesh or membrane. It's a vacuum cleaner, so dust and hair are the main way these mics will fail.

Mechanical and electrical notes
- Isolate the board from vibration. MEMS mics pick up vibration through the structure, and the LiDAR motor sits right below. Mount on silicone grommets or foam, not rigid standoffs.
- Keep it low. The cage top is usually the robot's highest point, so the board adds directly to under-furniture clearance. If you ever add a top-contact bump switch on the cage, plan the board around it.
- Digital mics don't pick up the LiDAR motor's electrical noise. Keep the PDM traces short; a 22–33 Ω series resistor on the clock is enough.
- Power: a 3.3 V regulator on the board, and ESD protection on the USB data lines at the connector.
- Hardware mute: add a switch that cuts power to the mics, with an LED showing when they're off. People are wary of a mic that roams their home. A hardware switch is cheap and more convincing than a software mute.
- Optional: a ring of a few WS2812 LEDs to show which direction the robot is listening.

What noise cancellation can realistically do

Set expectations before promising "noise cancellation":
- The fan is loud. A running vacuum is roughly 65–75 dBA at a mic about 15 cm from the fan. Four-mic beamforming buys about 6 dB plus whatever the post-filter adds. That helps, but won't make speech clear during full-power cleaning.
- The fan never moves relative to the mics. That is the one big advantage you have. An MVDR beamformer can "learn" the fan noise while the fan runs with nobody talking, and place a fixed null toward it. That works much better than generic noise suppression.
- Plan the interaction around it. The robot hears the wake word, drops the fan to low or off, and then listens for the command. Commands at full suction would stay unreliable.
- Echo cancellation: mic and speaker are on different clocks (USB vs I²S). PipeWire's WebRTC echo-cancel module copes with clock drift, but not perfectly. If you later want solid "barge-in" (talking over the robot's own voice prompts), the clean fix is to play one of the RP2040's spare channels as a loopback of the speaker signal. That can wait.

Software
- Linux sees a 4-channel USB microphone through ALSA or PipeWire.
- ODAS (IntRoLab) handles direction-finding and sound tracking, and there is an odas_ros package for ROS 2.
- Other options: openWakeWord for the wake word, and Vosk or whisper.cpp for speech recognition on a CM5.
- Pair it with the LiDAR: the mics give the speaker's direction and the LiDAR gives the distance.

Cheaper alternative: 2 mics on I²S, no MCU
- Two I²S MEMS mics on GPIO20, sharing the NS4168's clock lines. This gets you direction-finding with front/back ambiguity, mild beamforming and easy echo cancellation.
- It's a fine "lite" option, but it's limited to 2 mics and still runs a fast clock up the cage.

## USB, UART allocation

Put the Linux console to a UART (not USB). Then the single USB port can serve the mic board in normal use and only be needed for flashing, and neither job needs extra ICs.
- UART0 on GPIO14/15 as the Linux console. This is standard on both CM4 and CM5.
- SSH and Foxglove over Wi-Fi. A cable to a moving robot is awkward anyway.
- Flashing eMMC, if available (rpiboot): Has to stay on USB; there's no UART alternative. But it's only needed for eMMC modules, rarely, and only while the robot isn't running.
  - The two remaining USB jobs never happen at the same time. For flashing, the CM4 acts as a USB device to your PC. In normal running, it acts as the host for the mic board. So they can share one port.

Design (current schematic)
- CM console: 0.1" 1x5 header (CM_CONSOLE1), TTL-234X-3V3 cable compatible. (A 3-pin JST-SH like the Pi 5 debug connector was considered and not used.)
  - The STM32 link uses a separate UART; the CM4 has UART2–5 available through device-tree overlays.
- STM32 debug: 0.1" 1x5 UART header (STM32_DEBUG1) and a 1.27 mm 2x7 STDC14 header (JTAG1) for an STLINK-V3MINIE. STDC14 pin 3 (T_VCC) is a sense input; pin 11 (GNDDetect) is not connected.
- The CM reflashes the STM32 itself (STM32 UART bootloader via BOOT0/NRST from CM GPIOs, or SWD over CM GPIOs), so normal firmware updates need no probe.
- One internal USB header, for example a 4-pin JST-GH, wired to the CM4's USB 2.0 pins.
  - Normal use: the mic board plugs in here. Or makers can plug in a USB hub, a USB stick, or a USB-audio or ReSpeaker-style array; it's their choice.
  - Flashing: unplug the mic board, set the boot jumper (nRPIBOOT), and connect a JST-GH-to-USB-A adapter cable to the PC.
  - Power (VBUS): feed the header's 5 V from the carrier through a polyfuse. Leave VBUS unconnected in the flashing adapter cable so the PC and the robot never feed power into each other; the robot powers itself while flashing. It's worth checking the CM4 datasheet for whether `rpiboot` needs to sense VBUS.
- Host mode on CM4: the CM4's USB port is off by default. Add `[cm4]` then `otg_mode=1` in `config.txt`. That turns it on in host mode using the Pi's XHCI controller, which handles USB audio better than the older `dwc2` controller. The boot ROM still enters flashing mode when the nRPIBOOT jumper is set.
- CM5: use the same header and the same mic board, so there's one design for both modules. The CM5's extra USB 3 ports stay free for whatever makers want.
- The mic board is USB full-speed (12 Mbit/s), which puts little load on the port.

## Safety and power rails

Rule: if the STM32 firmware hangs, is held in reset or is being flashed, every motor, the pump and the LiDAR lose power.

Power rails (current schematic):

| Rail | Made by | Feeds | Switched by |
| --- | --- | --- | --- |
| BAT-VCC (11.6-16.8 V) | 4S battery | everything below | power-button latch (Q13 AO4407C, STM-PWR-CTRL) |
| VCC-3V3 | AP64501 buck (U21) | STM32 | POWER-EN |
| VCC-3V3-REG | from VCC-3V3 via Q16/Q17 | sensors, IMU, driver logic | STM32 (3.3V_EN) |
| 3.3VBAT | HT7533 LDO | STM32 VBAT (RTC keeps time) | always on |
| VCC-5V-REG | AP64501 buck (U22) | CM5, speaker amp, USB header, LiDAR and pump switches, VUS boost | STM32 (5V_EN) |
| VCC3V3_M2 | AP64501 buck (U24) | M.2 slot | CM (PCIE_PWR_EN) |
| USB-C VBUS 5 V | AP64501 buck (U25) + TMI6240 | phone (phone-as-compute option) | STM32 (PWR_EN) |
| VUS ≈ 14.5 V | MT3608 boost | carpet sensor | with VCC-5V-REG |
| VM-VBAT | BAT-VCC via Q1 AO4407C | wheels, brushes, fan | WD_OK AND ~VM-VBAT-EN |
| VM-5V-LIDAR | VCC-5V-REG via Q7002 AO3401 | whole LiDAR, laser included | WD_OK AND LiDAR-EN (low = on) |
| VM-5V-WATER-PUMP | VCC-5V-REG via Q8 AO3401 | water pump | WD_OK AND WATER-PUMPU-CTRL (low = on) |

RC charge-pump watchdog (WATCHDOG sheet):
- the STM32 toggles WDI in software (50-1000 Hz, ~50% duty) from a healthy control loop - never from a timer/PWM, which keeps running after the CPU hangs
- C7001 passes only WDI edges to Q7001 (AO3401); each falling edge tops up C7002 (10 µF) through R7003; R7004 (10k) bleeds it
- WD_OK ≈ 2.7 V while toggling; WDI stuck high, low or floating → below 1 V in ~100 ms, below 0.4 V in ~190 ms; 0 V at power-up
- the old STWD100 (U3), its OR gate (U4) and the JTAG-presence inverter (Q25) were removed: cutting actuator power is what makes the robot safe
- STM32 recovery: internal IWDG forced on by the hardware option byte (freeze it in debug via DBGMCU); the CM pulses STM32 NRST if the STM32 heartbeat stops

Each gated rail is WD_OK AND an MCU enable, without logic ICs:
- an AO3400 N-FET has its gate on WD_OK and its source on the MCU GPIO; it pulls the rail P-FET's gate low only when WD_OK is high and the GPIO is low
- a 100k pull-up to 3V3 on each GPIO keeps the rail off while the MCU pins float (reset, flashing)
- VM-VBAT: R165 10k gate pull-up for a fast turn-off; no soft start (a slow turn-off under motor current would overheat Q1). TODO check VM-VBAT max current vs Q1 rating; measure the fan controller's input capacitance (inrush)
- VM-5V-LIDAR: soft start R7006 10k + C7003 100 nF (≈1.5 ms on, ≈30 ms off) so the CM's 5 V doesn't dip
- VM-5V-WATER-PUMP: no soft start, so the pump can be PWM-driven
- PWM on an enable can only slow a gate-RC soft start; it can't soft-start a hard-switched FET

MOSFET line-up (consolidated 2026-09, 8 part numbers → 4):

| Role | Part | LCSC | Notes |
| --- | --- | --- | --- |
| all N-FETs | AO3400 (FOSAN) | C20628874 | 30 V, Vgs ±12 V, Vth 0.65-1.5 V, SOT-23 |
| P-FETs whose gate sees ≤ 5 V | AO3401 (FOSAN) | C20628875 | -30 V, Vgs ±12 V, SOT-23 |
| battery-side high-side switches (Q1, Q13) | AO4407C (AOS) | C469397 | -30 V, Vgs ±25 V, 11.5 mΩ, SOIC-8 |
| charger, 24 V DC_IN (Q12, Q14) | AOD407 | C6396162 | -60 V for hot-plug margin |

Any gate or drain that can see BAT-VCC (up to 16.8 V) needs Vds ≥ 30 V, and a gate swing that large needs Vgs ≥ 20 V.

## TODO

| Type | Qty | Spec |
| --- | --- | --- |
| LiDAR | 1 | 5V 0.35A max (about 1 A at spin-up), Mabuchi-style RF-500TB-14350 or similar; whole LiDAR on the switched VM-5V-LIDAR rail, motor low-side N-FET (Q20) |
| Main brush | 1 | DC 14.4-15V PRI-390SV-24100, JLS-395PH-2248A, RS-390WM-3107GCF or similar |
| Side brush | 1 | JGA25-310 geared DC motor, 12 V, ~150 RPM, metal gearbox, no encoder; mounted vertically, drives the brush directly via a custom coupler. Runs off the 14.4-16.8 V pack, so PWM-limit to ~12 V average. (Was DC 14.4V RC500-KW/14440/DV in a Roborock-style gearbox assembly; dropped because those assemblies only mate older, non tangle-resistant brushes.) |
| Mop | 2 | GM-RS385Y-24065 or similar, DC 14.4V |

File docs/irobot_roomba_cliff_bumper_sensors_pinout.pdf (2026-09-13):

R

L

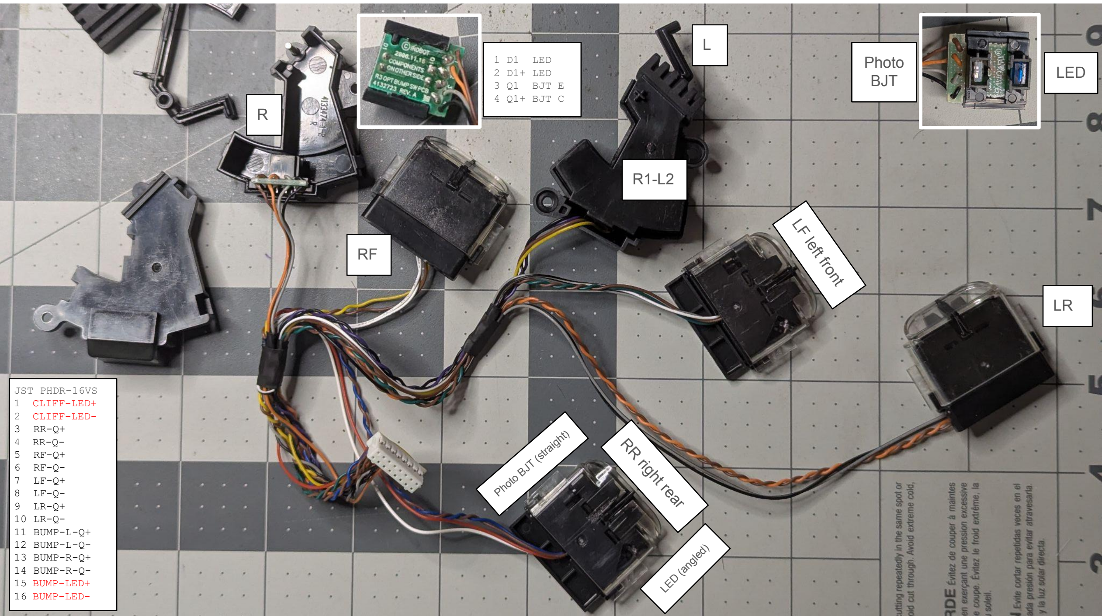
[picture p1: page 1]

1 D1 LED
2 D1+ LED
3 Q1 BJT E
4 Q1+ BJT C

R1-L2

RF

## RR right rear

# LF left front

LR

# LED Photo BJT

## LED (angled)

## Photo BJT (straight)

JST PHDR-16VS
1 | CLIFF-LED+
2 | CLIFF-LED-
3 | RR-Q+
4 | RR-Q-
5 | RF-Q+
6 | RF-Q-
7 | LF-Q+
8 | LF-Q-
9 | LR-Q+
10 LR-Q-11 BUMP-L-Q+
12 BUMP-L-Q-13 BUMP-R-Q+
14 BUMP-R-Q-
15 | BUMP-LED+
16 | BUMP-LED-

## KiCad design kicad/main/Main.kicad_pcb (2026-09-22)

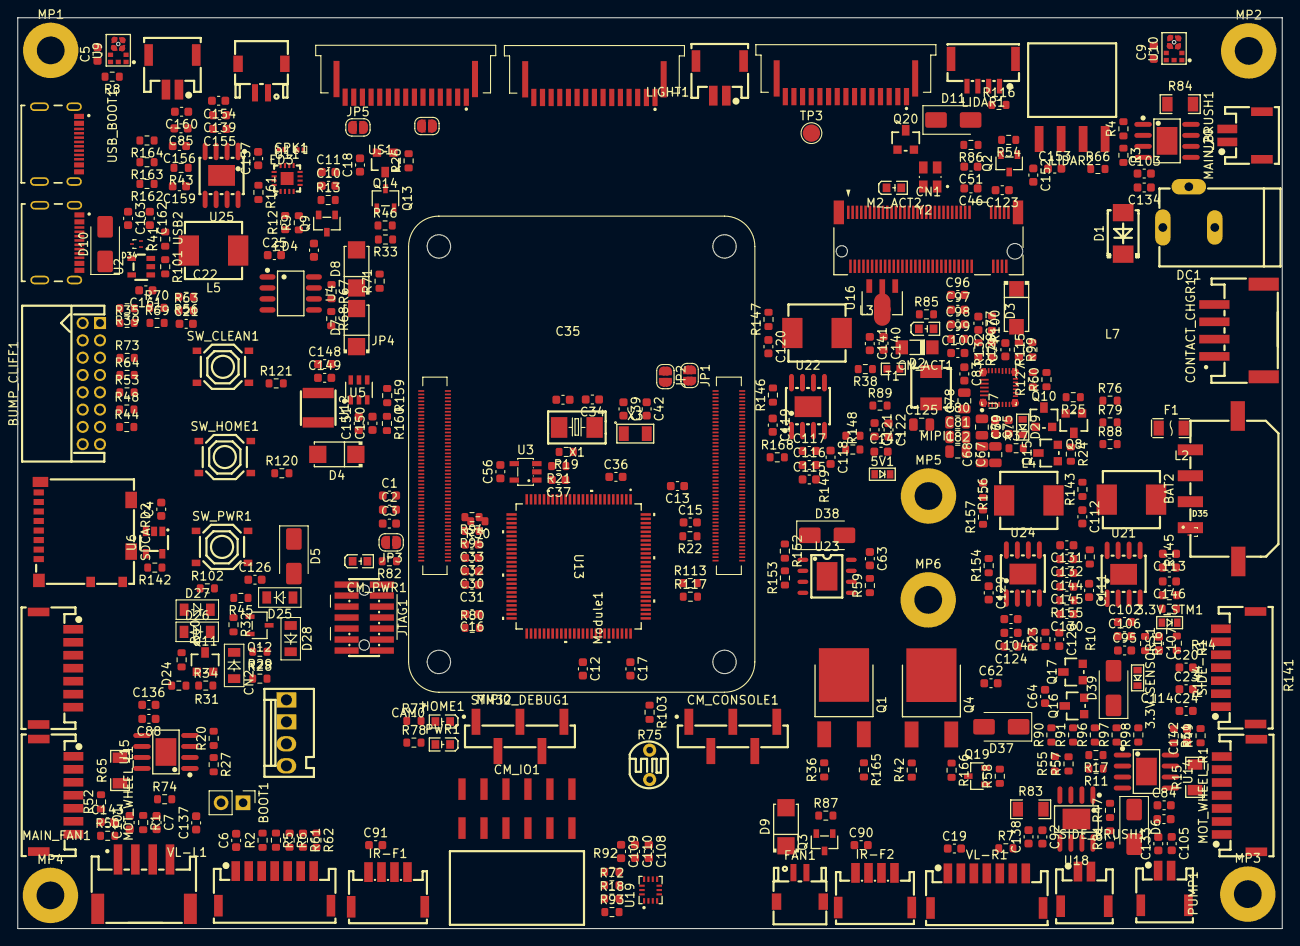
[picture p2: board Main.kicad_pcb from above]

Board: 4 copper layers, 146.1 x 105.2 mm, 392 parts (0 on the bottom side), 290 nets, no tracks yet.

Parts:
3.3V_SENSORS1: 3V3_SENSORS; LED0603-B
3.3V_STM1: 3V3-STM; LED0603-B
5V1: LED0603-B
BAT2: BATTERY; 436500412
BOOT1: Conn_01x02_Pin; PinHeader_1x02_P2.54mm_Vertical
BUMP_CLIFF1: S16B-PHDSS_LF_SN
C1, C2, C4, C25: 100nF/50V; C_0603_1608Metric
C3, C46, C62, C83, C95, C96, C97, C98, C99, C100, C104, C106, C115, C116, C123, C124, C134, C135, C136, C137, C138, C139, C140, C141, C150, C151, C154: 10uF/25V; C_0603_1608Metric
C5, C9, C12, C13, C15, C16, C30, C32, C36, C37, C51, C56, C109, C142, C143: 100nF/6.3V; C_0603_1608Metric
C6, C17, C19, C20, C23, C24, C31, C33, C64, C90, C91, C108, C113, C114, C131, C132, C144, C145, C146, C159, C160, C161: 10uF/6.3V; C_0603_1608Metric
C7, C101, C105: 150pF/50V; C_0603_1608Metric
C10, C163: 100nF/10V; C_0603_1608Metric
C11, C63, C121, C122, C133, C147, C148, C149, C152, C153: 10uF/10V; C_0603_1608Metric
C18, C21, C22, C84, C88, C92, C102, C103, C107, C111, C117, C118, C119, C126, C127, C128, C129, C155, C156, C157: 100nF/25V; C_0603_1608Metric
C34, C35: 22pF/50V; C_0603_1608Metric
C39, C42: 18pF/50V; C_0603_1608Metric
C67, C68, C69, C78, C80, C81, C82, C125: 10uF/50V; C_0805_2012Metric
C70: 4.7uF/10V; C_0603_1608Metric
C75, C79, C110: 47nF/50V; C_0603_1608Metric
C77: 1nF/50V; C_0603_1608Metric
C85, C112, C120, C130, C162: 1.2nF/50V; C_0603_1608Metric
CAM0: SFW15R-1STE1LF; AMPHENOL_SFW15R-1STE1LF
CM_ACT1: YLED0603B
CM_CONSOLE1: HX_PZ2_54-1X5P_TP-YQ
CM_IO1: HX_PM2_54-2X6P_WT
CM_PWR1: YLED0603B
CN1: 91302-85-067RDM
CN2: EV2400; A2543WV-4P
CONTACT_CHGR1: WAFER-PH2_0-4PWB
D1: SMBJ24A_C908801
D2: ZMM9V1_C2891750
D3: SMAJ18A_C148219
D4, D7, D8, D9: SS34_C8678
D5, D6, D10, D11, D37, D38, D39: SS34; D_SMA
D24, D25, D26, D27, D28: 1N4148; SOD123
D29: 3V3-STAT; LED0603-B
D34, D35: TPD2EUSB30DRTR; SOTFL35P100X50-3N
DC1: DC-005-5A-2_0
ED3, ED4: ESD5451N; ESD0402
F1: JFC1206-2200FS
FAN1: S2B-ZR-SM4A-TF_LF_SN
HOME1: YLED0603B
IR-F1, IR-F2: ZX-ZH1_5-4PWT
JP1, JP2, JP3, JP4, JP5: SolderJumper-2_P1.3mm_Open_RoundedPad1.0x1.5mm
JTAG1: STLINK-V3MINIE; FTSH-107-01-L-DV-K-A
L2, L3, L4, L5: CYA0630-3_3UH
L7: 1uH; GSM0420-1R0-M
LIDAR1: WAFER-GH1_25-4PWB
LIDAR2: HX_PM2_54-1X4P_WT
LIGHT1: ZX-ZH1_5-2PWT
M2_ACT2: YLED0603B
MAIN_BRUSH1: ZX-ZH1_5-2PWT
MAIN_FAN1: WAFER-PH2_0-4PWB
MIPI0, MIPI1: SFW15R-1STE1LF; AMPHENOL_SFW15R-1STE1LF
MOT_WHEEL_L1: ZX-ZH1_5-7PWT
MOT_WHEEL_R1: ZX-ZH1_5-7PWT
MP1, MP2, MP3, MP4, MP5, MP6: M3 x 1.5mm; MountingHole_3.2mm_M3_Pad
Module1: ComputeModule5-CM5; Raspberry-Pi-5-Compute-Module
PUMP1: ZX-ZH1_5-2PWT
PWR1: YLED0603B
Q1, Q4: AOD407_C6396162
Q2, Q3, Q9, Q19: 2302V
Q8, Q10, Q16, Q17: AO3401; SOT23-3D
Q11, Q14, Q15: 2N3904; SOT23-3D
Q12, Q13: 2N3906_C49023424
Q20: AO3400; SOT23-3D
R1, R18, R21, R22, R23, R25, R31, R32, R34, R45, R49, R50, R51, R52, R67, R72, R76, R81, R90, R91, R92, R93, R102, R103, R132, R142, R152, R159: 10k; R_0603_1608Metric
R2, R7, R39, R44, R48, R53, R61, R62, R64, R73: 47k; R_0603_1608Metric
R3, R4, R8, R10, R11, R13, R16, R17, R20, R27, R29, R38, R40, R41, R43, R54, R55, R56, R57, R58, R59, R63, R69, R70, R74, R115, R116, R153, R165, R166, R168: 100k; R_0603_1608Metric
R5, R6, R24, R26, R33, R46, R149, R164: 2.2k; R_0603_1608Metric
R9, R12, R19: 0; R_0603_1608Metric
R14, R28, R37, R66, R68, R71, R77, R78, R82, R85, R86, R87, R89, R98, R113, R120, R121: 1k; R_0603_1608Metric
R15, R65: RL12FTNR250
R30: 330; R_0603_1608Metric
R35: 22; R_0603_1608Metric
R36, R42, R79, R80, R88, R94, R95, R96, R97, R117, R141, R146, R154, R161: 10; R_0603_1608Metric
R47, R147, R162: 20k; R_0603_1608Metric
R60: 30.31k; R_0603_1608Metric
R75: GL5537-1
R83: RL12FTNR300
R84: RLH12FTCR110
R99, R101: 215k; R_0603_1608Metric
R100: 100; R_0603_1608Metric
R127: 5.24k; R_0603_1608Metric
R129: 17.4k; R_0603_1608Metric
R143, R148, R155, R163: 12k; R_0603_1608Metric
R144, R156: 69.8k; R_0603_1608Metric
R145, R157: 22.1k; R_0603_1608Metric
R160: 324k; R_0603_1608Metric
SDCARD2: 1040310811
SIDE-L1: ZX-ZH1_5-7PWT
SIDE-R1: ZX-ZH1_5-7PWT
SIDE_BRUSH1: ZX-ZH1_5-2PWT
SPK1: ZX-ZH1_5-2PWT
STM32_DEBUG1: HX_PZ2_54-1X5P_TP-YQ
SW_CLEAN1: TS-1187A-B-A-B
SW_HOME1: TS-1187A-B-A-B
SW_PWR1: TS-1187A-B-A-B
T1: NTCG164KF104FT1
TP3: TestPoint; TestPoint_Pad_D2.0mm
U2: TMI6240
U3: STWD100NYWY3F
U4: RS8422XK
U5: MT3608
U6: RT9742GGJ5
U7: BQ25792RQMR
U9, U10: ICS-43434_C5656610
U11: MAX98357AETE_T
U12: XRNR4030-10UH_M
U13: STM32G473VCT6; LQFP100-14x14mm
U14, U15, U18, U20: DRV8870DDAR
U16: HT7533-1_C14289
U19: ICM-42607-P
U21, U22, U24, U25: AP64501SP-13
U23: BV1HAL45EFJ-E2
US1: S2B-ZR-SM4A-TF_LF_SN
USB2: USB4215-03-A_REVA; GCT_USB4215-03-A_REVA
USB_BOOT1: USB4215-03-A_REVA; GCT_USB4215-03-A_REVA
VL-L1: ZX-ZH1_5-7PWT
VL-R1: ZX-ZH1_5-7PWT
X1: ABM3-8_000MHZ-D2Y-T
X3: XKXEL89CII-SUAYLC-32_768K
Y2: ASEK-32.768KHZ-LRT; XTAL_ASEK-32.768KHZ-LRT

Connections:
3.3V-PI: C1.1, Module1.78 (GPIO_VREF(1.8v/3.3v_Input)), Module1.84 (+3.3v_(Output)), Module1.86 (+3.3v_(Output)), R13.1, R23.1, R85.1, R142.1, U6.5 (VIN)
3.3VBAT: C36.1, C141.1, U13.6 (VBAT), U16.3 (Vout)
/BATTERY-CHARGER/D+: D34.1 (D+), U13.73 (PA12), USB2.A6 (DP1), USB2.B6 (DP2)
/BATTERY-CHARGER/D-: D34.2 (D-), U13.72 (PA11), USB2.A7 (DN1), USB2.B7 (DN2)
/BATTERY-CHARGER/ID: BAT2.3, U13.53 (PB14)
/BATTERY-CHARGER/NTC: BAT2.2, R60.2, R127.2, U7.16 (TS)
/BATTERY-CHARGER/P+/C+: F1.1, R100.2, U7.22 (BAT), U7.23 (BAT)
/BATTERY-CHARGER/PWR_EN: R43.1, U13.79 (PC10), U25.3 (EN)
/BATTERY-CHARGER/REGN: C70.2, D29.1, R115.2, R127.1, U7.5 (REGN)
/BATTERY-CHARGER/SCL: CN2.2, U7.14 (SCL), U13.67 (PC8)
/BATTERY-CHARGER/SDA: CN2.3, U7.15 (SDA), U13.68 (PC9)
/BATTERY-CHARGER/VBUS: C163.1, D10.2 (K), U2.5 (VOUT), USB2.A4_B9 (VBUS_A), USB2.B4_A9 (VBUS_B)
/BATTERY-CHARGER/~INT: R132.1, U7.21 (INT#), U13.54 (PB15)
/BUTTON-LED/CLEAN-BTN: R121.1, SW_CLEAN1.3 (C), SW_CLEAN1.4 (D), U13.82 (PD0)
/BUTTON-LED/HOME-BTN: R120.1, SW_HOME1.3 (C), SW_HOME1.4 (D), U13.87 (PD5)
/BUTTON-LED/LED-HOME: R77.1, U13.7 (PC13)
/BUTTON-LED/LED-PWR: R78.1, U13.19 (PF2)
/BUTTON-LED/POWER-BTN: C126.2, D25.2 (K), R102.1, SW_PWR1.3 (C), SW_PWR1.4 (D)
/CAMERA/CAM_GPIO0: CAM0.11, MIPI0.11, Module1.97 (CAM_GPIO0)
/CAMERA/CAM_GPIO1: JP3.2 (B), Module1.100 (CAM_GPIO1)
/CAMERA/CM4_CAM0_C_N: CAM0.8, Module1.140 (USB3-0-TX_N)
/CAMERA/CM4_CAM0_C_P: CAM0.9, Module1.142 (USB3-0-TX_P)
/CAMERA/CM4_CAM0_D0_N: CAM0.2, Module1.128 (USB3-0-RX_N)
/CAMERA/CM4_CAM0_D0_P: CAM0.3, Module1.130 (USB3-0-RX_P)
/CAMERA/CM4_CAM0_D1_N: CAM0.5, Module1.134 (USB3-0-D_P)
/CAMERA/CM4_CAM0_D1_P: CAM0.6, Module1.136 (USB3-0-D_N)
/CAMERA/ID_SC: CAM0.13, MIPI1.13, Module1.35 (ID_SC)
/CAMERA/ID_SD: CAM0.14, MIPI1.14, Module1.36 (ID_SD)
/CAMERA/IO1: CAM0.12, JP3.1 (A), MIPI0.12, TP3.1 (1_1)
/CAMERA/MIPI0_C_N: MIPI0.8, Module1.127 (MIPI0_C_N)
/CAMERA/MIPI0_C_P: MIPI0.9, Module1.129 (MIPI0_C_P)
/CAMERA/MIPI0_D0_N: MIPI0.2, Module1.115 (MIPI0_D0_N)
/CAMERA/MIPI0_D0_P: MIPI0.3, Module1.117 (MIPI0_D0_P)
/CAMERA/MIPI0_D1_N: MIPI0.5, Module1.121 (MIPI0_D1_N)
/CAMERA/MIPI0_D1_P: MIPI0.6, Module1.123 (MIPI0_D1_P)
/CAMERA/MIPI1_C_N: MIPI1.8, Module1.187 (MIPI1_C_N)
/CAMERA/MIPI1_C_P: MIPI1.9, Module1.189 (MIPI1_C_P)
/CAMERA/MIPI1_D0_N: MIPI1.2, Module1.175 (MIPI1_D0_N)
/CAMERA/MIPI1_D0_P: MIPI1.3, Module1.177 (MIPI1_D0_P)
/CAMERA/MIPI1_D1_N: MIPI1.5, Module1.181 (MIPI1_D1_N)
/CAMERA/MIPI1_D1_P: MIPI1.6, Module1.183 (MIPI1_D1_P)
/CAMERA/MIPI1_IO0: JP4.2 (B), Module1.37 (GPIO7)
/CAMERA/MIPI1_IO1: JP5.2 (B), Module1.39 (GPIO8)
/CAMERA/SCL0: MIPI0.13, Module1.80 (SCL0)
/CAMERA/SDA0: MIPI0.14, Module1.82 (SDA0)
/CARPET-SENSOR/ECHO: C18.2, C21.2, US1.1
/CARPET-SENSOR/ECHO_ADC: R71.2, U13.43 (PE12)
/CARPET-SENSOR/HI: R24.1, U13.41 (PE10)
/CARPET-SENSOR/LO: R26.1, U13.42 (PE11)
/CLIFF/BUMP-L-Q+: BUMP_CLIFF1.11, R48.1, U13.26 (PA4)
/CLIFF/BUMP-R-Q+: BUMP_CLIFF1.13, R44.1, U13.27 (PA5)
/CLIFF/BUMPER_LED_EN: BUMP_CLIFF1.16, U13.18 (PC3)
/CLIFF/CLIFF_LED_EN: BUMP_CLIFF1.2, U13.16 (PC1)
/CLIFF/LF-Q+: BUMP_CLIFF1.7, R64.1, U13.25 (PA3)
/CLIFF/LR-Q+: BUMP_CLIFF1.9, R53.1, U13.22 (PA2)
/CLIFF/RF-Q+: BUMP_CLIFF1.5, R73.1, U13.21 (PA1)
/CLIFF/RR-Q+: BUMP_CLIFF1.3, R39.1, U13.20 (PA0)
/CM5-GPIO/CONSOLE_RXD: CM_CONSOLE1.4, Module1.51 (GPIO15)
/CM5-GPIO/CONSOLE_TXD: CM_CONSOLE1.5, Module1.55 (GPIO14)
/CM5-GPIO/GPIO06: Module1.30 (GPIO6), Q9.1 (G), R13.2
/CM5-GPIO/GPIO11: CM_IO1.2, Module1.38 (GPIO11)
/CM5-GPIO/GPIO12: CM_IO1.7, Module1.31 (GPIO12)
/CM5-GPIO/GPIO13: CM_IO1.6, Module1.28 (GPIO13)
/CM5-GPIO/GPIO16: Module1.29 (GPIO16), VL-R1.7
/CM5-GPIO/GPIO17: Module1.50 (GPIO17), R2.1, VL-L1.3, VL-R1.3
/CM5-GPIO/GPIO22: CM_IO1.3, Module1.46 (GPIO22)
/CM5-GPIO/GPIO23: CM_IO1.4, Module1.47 (GPIO23)
/CM5-GPIO/GPIO24: CM_IO1.5, Module1.45 (GPIO24)
/CM5-GPIO/GPIO25: Module1.41 (GPIO25), R61.2, VL-L1.6
/CM5-GPIO/GPIO26: Module1.24 (GPIO26), R62.2, VL-L1.7
/CM5-GPIO/GPIO27: Module1.48 (GPIO27), R7.2, VL-R1.6
/CM5-GPIO/I2S_DOUT: Module1.25 (GPIO21), U11.1 (DIN)
/CM5-GPIO/PI_DONE: Module1.40 (GPIO9), U13.92 (PB5)
/CM5-GPIO/PI_SHUTDOWN: Module1.44 (GPIO10), U13.93 (PB6)
/CM5-GPIO/PMIC_EN: Module1.99 (PMIC_ENABLE), U13.52 (PB13)
/CM5-GPIO/RUN_PG: Module1.92 (PWR_BUT), U13.39 (PE8)
/CM5-GPIO/SCL1: Module1.56 (GPIO3), R6.2, VL-L1.5, VL-R1.5
/CM5-GPIO/SDA1: Module1.58 (GPIO2), R5.2, VL-L1.4, VL-R1.4
/CM5-GPIO/SD_CLK: Module1.57 (SD_CLK), SDCARD2.5 (CLK)
/CM5-GPIO/SD_CMD: Module1.62 (SD_CMD), SDCARD2.3 (CMD)
/CM5-GPIO/SD_DAT0: Module1.63 (SD_DAT0), SDCARD2.7 (DAT0)
/CM5-GPIO/SD_DAT1: Module1.67 (SD_DAT1), SDCARD2.8 (DAT1)
/CM5-GPIO/SD_DAT2: Module1.69 (SD_DAT2), SDCARD2.1 (DAT2)
/CM5-GPIO/SD_DAT3: Module1.61 (SD_DAT3), SDCARD2.2 (CD/DAT3)
/CM5-GPIO/SD_PWR_ON: Module1.75 (SD_PWR_ON), R142.2, U6.4 (EN/EN#)
/CM5-GPIO/UART2_RX: Module1.34 (GPIO5), R94.2
/CM5-GPIO/UART2_TX: Module1.54 (GPIO4), R95.2
/CM5-HIGHSPEED/D+: D35.1 (D+), Module1.105 (USB2_P), USB_BOOT1.A6 (DP1), USB_BOOT1.B6 (DP2)
/CM5-HIGHSPEED/D-: D35.2 (D-), Module1.103 (USB2_N), USB_BOOT1.A7 (DN1), USB_BOOT1.B7 (DN2)
/CM5-HIGHSPEED/PCIE_CLK_N: CN1.53, Module1.112 (PCIe_CLK_N)
/CM5-HIGHSPEED/PCIE_CLK_P: CN1.55, Module1.110 (PCIe_CLK_P)
/CM5-HIGHSPEED/PCIE_CLK_nREQ: CN1.52, Module1.102 (PCIe_nCLKREQ)
/CM5-HIGHSPEED/PCIE_PWR_EN: JP2.1 (A), R10.1, R23.2, U24.3 (EN)
/CM5-HIGHSPEED/PCIE_RX_N: CN1.43, Module1.118 (PCIe_RX_N)
/CM5-HIGHSPEED/PCIE_RX_P: CN1.41, Module1.116 (PCIe_RX_P)
/CM5-HIGHSPEED/PCIE_TX_N: CN1.49, Module1.124 (PCIe_TX_N)
/CM5-HIGHSPEED/PCIE_TX_P: CN1.47, Module1.122 (PCIe_TX_P)
/CM5-HIGHSPEED/PCIE_nRST: CN1.50, Module1.109 (PCIe_nRST)
/CM5-HIGHSPEED/PCIE_nWAKE: CN1.54, JP1.1 (A)
/FRONT SENSORS/IR-F-RX1: IR-F1.4, U13.46 (PE15)
/FRONT SENSORS/IR-F-RX2: IR-F2.4, R80.1
/FRONT SENSORS/LIGHT-ON: Q2.1 (G), R54.1, U13.59 (PD12)
/IMU-FSYNC: U13.86 (PD4), U19.7 (FSYNC)
/IMU-INT1: R93.2, U13.85 (PD3), U19.4 (INT1/INT)
/IMU-INT2: R92.2, U13.89 (PD7), U19.9 (INT2)
/IMU/IMU-SCL: R72.2, U13.70 (PA9), U19.13 (AP_SCL/AP_SCLK)
/IMU/IMU-SDA: R18.2, U13.69 (PA8), U19.14 (AP_SDA/AP_SDIO/AP_SDI)
/LiDAR/LiDAR-EN: LIDAR2.2, U13.56 (PD9)
/LiDAR/LiDAR-MOTOR-CTRL: LIDAR1.1, Q20.1 (G), R116.2, U13.17 (PC2)
/LiDAR/LiDAR-RXD: R66.1, R113.2
/LiDAR/LiDAR-TXD: LIDAR1.3, R117.2
/MAIN-BRUSH MOTOR/MAIN-BRUSH-CURRENT-ADC: R84.2, U13.28 (PA6), U20.7 (ISEN)
/MAIN-BRUSH MOTOR/MAIN-BRUSH-IN1: R3.1, U13.61 (PD14), U20.3 (IN1)
/MAIN-BRUSH MOTOR/MAIN-BRUSH-IN2: R4.1, U13.62 (PD15), U20.2 (IN2)
/MAIN-FAN/MAIN-FAN-S-CTRL: C7.1, MAIN_FAN1.2, R74.1, U13.83 (PD1)
/MAIN-FAN/MAIN-FAN-S-SENSE: C101.1, MAIN_FAN1.1, R1.2, U13.40 (PE9)
/MCU-STM32/3.3V_EN: C64.2, D39.1 (A), R90.1, R91.1, R96.1, R97.1, U13.90 (PB3)
/MCU-STM32/3.3V_JTG: D5.2 (A), JTAG1.03 (3), U3.3 (EN)
/MCU-STM32/5V_EN: R168.2, U13.91 (PB4), U22.3 (EN)
/MCU-STM32/BOARD_FAN: R87.1, U13.71 (PA10)
/MCU-STM32/I2C4_SCL: SIDE-L1.6, SIDE-R1.6, U13.65 (PC6)
/MCU-STM32/I2C4_SDA: SIDE-L1.7, SIDE-R1.7, U13.66 (PC7)
/MCU-STM32/PWR-BTN-SENSE: D25.1 (A), U13.38 (PE7)
/MCU-STM32/SIDE-BRUSH-CURRENT-ADC: R83.2, U13.60 (PD13), U18.7 (ISEN)
/MCU-STM32/SIDE-BRUSH-IN1: R55.1, U13.10 (PF9), U18.3 (IN1)
/MCU-STM32/SIDE-BRUSH-IN2: R57.1, U13.11 (PF10), U18.2 (IN2)
/MCU-STM32/SIDE-PROXI-CE-L: SIDE-L1.5, U13.4 (PE5)
/MCU-STM32/SIDE-PROXI-CE-R: SIDE-R1.5, U13.2 (PE3)
/MCU-STM32/SIDE-PROXI-GPIO-L: SIDE-L1.4, U13.3 (PE4)
/MCU-STM32/SIDE-PROXI-GPIO-R: SIDE-R1.4, U13.1 (PE2)
/MCU-STM32/STM32-RX: JTAG1.13, R95.1, STM32_DEBUG1.4, U13.31 (PC5)
/MCU-STM32/STM32-SWCLK: JTAG1.06 (6), U13.77 (PA14)
/MCU-STM32/STM32-SWDIO: JTAG1.04 (4), U13.76 (PA13)
/MCU-STM32/STM32-TX: JTAG1.14, R94.1, STM32_DEBUG1.5, U13.30 (PC4)
/MCU-STM32/STM-PWR-CTRL: R28.2, U13.78 (PA15)
/MCU-STM32/USART2-IR-L-RX: SIDE-R1.3, U13.88 (PD6)
/MCU-STM32/USART4-IR-R-RX: SIDE-L1.3, U13.80 (PC11)
/MCU-STM32/WATER-PUMP-SENSE-ADC: R47.1, R81.2, U13.29 (PA7)
/MCU-STM32/WATER-PUMPU-CTRL: R25.1, R76.1, R79.1, R88.1, U13.15 (PC0)
/MCU-STM32/WDO: U3.4 (WDI), U13.55 (PD8)
/MCU-STM32/WHEEL-M-L-F-ADC: R65.2, U13.58 (PD11), U15.7 (ISEN)
/MCU-STM32/WHEEL-M-LEFT-DROP: MOT_WHEEL_L1.7, R50.2, U13.33 (PB1)
/MCU-STM32/WHEEL-M-LEFT-ENCODE-A: MOT_WHEEL_L1.4, R52.2, U13.44 (PE13)
/MCU-STM32/WHEEL-M-LEFT-IN1: R20.1, U13.97 (PE0), U15.3 (IN1)
/MCU-STM32/WHEEL-M-LEFT-IN2: R27.1, U13.98 (PE1), U15.2 (IN2)
/MCU-STM32/WHEEL-M-R-F-ADC: R15.2, U13.57 (PD10), U14.7 (ISEN)
/MCU-STM32/WHEEL-M-RIGHT-DROP: MOT_WHEEL_R1.7, R49.2, U13.32 (PB0)
/MCU-STM32/WHEEL-M-RIGHT-ENCODE-A: MOT_WHEEL_R1.4, R51.2, U13.45 (PE14)
/MCU-STM32/WHEEL-M-RIGHT-IN1: R11.1, U13.94 (PB7), U14.3 (IN1)
/MCU-STM32/WHEEL-M-RIGHT-IN2: R17.1, U13.96 (PB9), U14.2 (IN2)
/MCU-STM32/~RST: C37.1, JTAG1.12, Q19.1 (G), R21.1, R58.1, R59.1, U3.1 (WDO), U13.14 (PG10-NRST), U23.5 (EN)
/POWER/POWER-EN: D24.2 (K), Q11.3 (C), R16.1, R29.2, R40.1, U21.3 (EN)
/SPEAKER-MIC/BCLK: Module1.49 (GPIO18), U9.4 (SCK), U10.4 (SCK), U11.16 (BCLK)
/SPEAKER-MIC/DOUT: Module1.27 (GPIO20), R8.1, U9.6 (SD), U10.6 (SD)
/SPEAKER-MIC/LRCLK: Module1.26 (GPIO19), U9.1 (WS), U10.1 (WS), U11.14 (LRCLK)
BAT-VCC: C83.1, C95.1, C96.2, C97.2, C98.2, C99.2, C100.2, C102.1, C104.1, C106.1, C115.1, C116.1, C117.1, C124.1, C127.1, C139.1, C154.1, C155.1, D2.1 (K), D3.1, D27.1 (A), Q1.3 (S), Q4.3 (S), R165.1, R166.1, U7.25 (SYS), U21.2 (VIN), U22.2 (VIN), U24.2 (VIN), U25.2 (VIN)
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

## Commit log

2026-09-09 Revise motor and component specifications in SPEC.md
    Updated specifications for various components including motors and sensors. Changed water pump specifications and added details for side brush FlexiArm assembly.
2026-09-09 Revise fan specifications and add new tables
    Updated specifications for various suction fans, including pinouts and performance metrics. Added new tables for fan models and their respective details.
2026-09-10 Revise specifications and update component details
    Updated specifications for cliff sensors, battery, and connectors. Changed 'TBD' to 'TODO' and clarified component details.
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2026-09-13 Revise fan specs and connector information in SPEC.md
    Updated fan specifications and connector details in the documentation.
2026-09-13 Revise fan details and add interchangeability note
    Updated fan specifications and added note about interchangeability.
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2026-09-13 Cliff/bumpers connector
    [ANTI-FALL-IR-SENSORs.kicad_sch, BMS-SYSTEM-POWER.kicad_sch, BUTTON-LEDs .kicad_sch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]
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2026-09-13 Second review round
    [ANTI-FALL-IR-SENSORs.kicad_sch, BMS-SYSTEM-POWER.kicad_sch, BUTTON-LEDs .kicad_sch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]
2026-09-15 Cliff/bumper connector reverse engineered
    [CLIFF.kicad_sch, Carpet-sensor.kicad_sch, Main.kicad_pcb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]
2026-09-17 Add master fuse
    [Battery-Charger.kicad_sch, CM5-GPIO.kicad_sch, M.2.kicad_sch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]
2026-09-19 Revise motor and sensor specifications in SPEC.md
    Updated specifications for various motors and sensors, including details on voltage, current, and compatibility with specific models.
2026-09-21 STM32 power rail switch
    [BMS-SYSTEM-POWER.kicad_sch, BUTTON-LEDs .kicad_sch, Battery-Charger.kicad_sch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]
2026-09-26 Update Power Control sch, Charger sch, Speaker + Mic, JTAG and Watch Dog
    **Power Control:** Replaced the BJT with a MOSFET. The MCU hang condition is not covered yet.
    [BMS-SYSTEM-POWER.kicad_sch, Battery-Charger.kicad_sch, CM5-GPIO.kicad_sch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]
2026-09-27 Fix Netclass, no other changes
    [MIPI-CAMERA.kicad_sch]
2026-09-27 Fix Q20 gate GND short
    [LiDAR .kicad_sch]
2026-09-27 Claude added RC watchdog
    [WATCHDOG.kicad_sch]
2026-09-28 Added watchdog safety
    [WATER-PUMP.kicad_sch]
2026-09-28 Replaced slow P-FET with resistor
    [Carpet-sensor.kicad_sch]
2026-09-28 Change N-MOSFET part
    [Front-Sensors.kicad_sch]
2026-09-28 Remove VM-5V; add VM-VBAT watchdog safety
    [BMS-SYSTEM-POWER.kicad_sch]
2026-09-28 Reassigned CARPET-SENSOR-HI to VM-VBAT-EN
    [STM32G473.kicad_sch]
2026-09-28 Cleaned up schematic filenames
    [Carpet-sensor.kicad_sch, Front Sensors.kicad_sch, LiDAR .kicad_sch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]
2026-09-28 Cleanup; renamed WDO to WDI
    [Main.kicad_sch, STM32G070RBT6.kicad_sch, STM32G473.kicad_sch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]
2026-10-02 Assigned footprints
    [Battery-Charger.kicad_sch, MIPI-CAMERA.kicad_sch, SYSTEM-POWER.kicad_sch]
2026-10-09 SPEC: one RGB camera on the STM32; JGA25-310 side brush motor
    Front sensors: the 2x OV5647 NIR stereo pair with structured
    illumination becomes one parallel-interface (DVP) RGB camera, pitched
    down to image the floor and obstacles up to robot height, with a white
    torchlight. It is read by the STM32 so it also works with an old
    smartphone as compute. Open: the STM32G473 has no DCMI, so capture needs
    GPIO+DMA, an SPI/FIFO module or a bridge MCU; and whether to keep the
    MIPI connectors as a Pi-only option.
    VL53L7 FoV corrected to ~63° horizontal each (~126° for two).
    Side brush motor: JGA25-310 12 V ~150 RPM geared motor, direct drive,
    PWM-limited to ~12 V on the 14.4-16.8 V pack.
    Co-Autho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
2026-10-09 SPEC: tentative Pi Pico-class MCU as the camera bridge
    The STM32G473 has no DCMI, so tentatively an RP2040/RP2350 captures the
    DVP camera with PIO and passes frames to the STM32 over SPI or UART.
    Notes the QFN-only package (a castellated module keeps it hand-solderable)
    and the USB FS bandwidth limit for raw frames to a phone.
2026-10-27 Add main-phone: v1 board with a smartphone as the compute
    kicad/main-phone is a fork of the Pi carrier for the first board: an
    Android phone talks to the STM32 over USB-C, no Pi, cameras, M.2, SD,
    speaker or mopping. The Pi board (kicad/main) stays in the plans.
    v1 board:
    - USB-C CC1/CC2 to the STM32 UCPD; reverse-block FETs for the TMI6240
    - front ToF on I2C4; LiDAR UART TX/RX unswapped
    - power control: charger rail-hold, ~4-9 s hardware off timer
    - 20 V input: SMAJ22A TVS, 50 V DC_IN caps, DC_IN sense to PB15
    - low-profile DC-044A-20A barrel jack (footprint + 3D model added)
    - on-board ITR9606 bumpers in parallel with the harness bumpers
    - carpet drive AC-coupled; right-angle 1x5 for LiDA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
2026-10-27 Charging dock rev 2; main-phone bucks AP64501 -> TPS54560B
    Charging dock (kicad/charging-dock), redesigned:
    - CH32V003F4P6 control (Arduino core, ch32fun, PlatformIO)
    - robot detection: resistance-signature probe before DOCK+ goes live
    - AO4407C soft-start output switch, 50 mOhm + INA180A1 current sense
    - NEC IR beacon: two 3x TSAL6200 strings, AC-coupled gates
    - 20 V input: DC-044A-20A, 5 A fuse, SMAJ22A, HT7533-1
    - refs 8xxx for the one-panel plan; uses the shared ../main libraries
    - removed the orphan sheets, the old local library copy and an unrelated PDF
    - README with pin map, detection math, firmware rules, layout notes
    main-phone: U21/U22 TPS54560B (AP64501 out of stock) with SS56 ca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
2026-10-28 Front sensors rev 2: IR receivers onto main-phone, ToF board x2 on JST SH
    - main-phone FRONT SENSORS: IR-F1/IR-F2 connectors replaced by two
    side-looking IRM-V838M3-C receivers on the board (U7501 left, U7502
    right) with 100R + 10uF filters; IRM-H638T is top-looking
    - VL-L1/VL-R1: ZX-SH1.0-7PWT (JST SH compatible), same pinout
    - kicad/front-sensors: one VL53L7 breakout fitted twice, refs 83xx, no
    pull-ups (main board has them), RSVD6 47k, ferrite to AVDD; the sensor
    is hand-placed (not in the JLC BOM/CPL); uses the shared ../main libs
    - shared JLCImport: VL53L7, BLM18PG121SN1D, IRM-V838M3-C, ZX-SH1_0-7PWT
    - docs: SPEC, READMEs, new front-sensors README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
2026-10-28 Side sensor board rev 2 (VL53L0X + IRM-H638T, JST SH); mounting holes on dock and sensor boards
    - kicad/side-sensors: VL53L0X (C91199) replaces the NRND VL6180 and its 2.8 V LDO;
    top-looking IRM-H638T replaces the TSOP38238; ZX-SH1.0-7PWT connector, same pinout;
    10k XSHUT/GPIO1 pull-ups, no local I2C pull-ups; refs 84xx; libs from ../main
    - main-phone SIDE-R1: ZX-ZH1.5-7PWT -> ZX-SH1.0-7PWT
    - mounting holes: dock 4x M3 (H8201-H8204), ToF board 2x M2 (H8301/H8302),
    side board 2x M2 (H8401/H8402)
    - JLCImport: VL53L0CXV0DH_1 symbol, footprint, 3D model
    - docs: side board README, SPEC, READMEs; IRM-H638T pinout confirmed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
2026-10-28 main-phone: vertical debug headers (STM32_DEBUG1, JTAG1), reached from the top
    - STM32_DEBUG1: PZ254R-11-05P right angle -> PZ254V-11-05P vertical (C492404)
    - JTAG1: 2x7 1.27 mm right angle -> SMD vertical PZ1.27-2x7PTP-L7.2 (C55099228), STDC14 pinout
    - JLCImport: PZ1_27-2X7P-TP symbol, footprint, 3D model
    - same pin numbers; netlist and ERC unchanged otherwise; docs updated
2026-10-29 main-phone: free MCU pins; 2x11 spare header with UART and I2C
    - LiDAR rail enable joins ~VM-VBAT-EN (PE10); PD9 freed
    - IMU FSYNC/INT2 go to J7301 instead of the MCU; FSYNC 100k pull-down (R7601); PD4/PD7 freed
    - one open-drain ToF interrupt (PD12) for both VL53L7s and the side VL53L0X; PC8/PE2 freed
    - right VL53L7 LPn held up by R7307, no MCU pin; PE8 freed
    - IMU moved from I2C2 to I2C4 (R18/R72 not fitted); PA8/PA9 freed;
    R7315 keeps PA9 (UCPD DBCC1) pulled up for dead-battery Rd on CC1
    - PWR_EN moved PC10 -> PD7; PC10/PC11 are a spare UART
    - J7301 2x6 -> 2x11: 3.3 V, 5 V, I2C4, UART, 12 spare GPIO, IMU FSYNC/INT2, GND
    - docs: SPEC, main-phone and side-sensor READMEs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
2026-10-29 Cliff sensor board (IR333-A + PT333-3B, no lenses); main board drops the Roomba harness
    - kicad/cliff-sensor: new board, fitted 6x. Narrow-beam 5 mm IR LED and black-lens
    phototransistor, 18 mm apart, tilted so the beams cross at the floor (tilt sets the
    reference distance). 150R LED resistor, SH 4-pin vertical (ZX-SH1.0-4PLT). Refs 85xx.
    - main-phone CLIFF sheet: BUMP_CLIFF1 (Roomba 2x8 harness), R30, R35 removed; six SH 4-pin
    connectors CLIFF-LF1..RR1; Q7701 (AO3400) switches all cliff LEDs from CLIFF_LED_EN
    (R7703 pull-down); 47k pull-ups incl. new R7701/R7702 for cliff LM (PD9) / RM (PE8)
    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
2026-10-29 Rear docking IR board and Hall sensor board; main-board connectors
    - kicad/rear-ir: 2x top-looking IRM-H638T with per-receiver 100R + 10uF filters, SH 4-pin
    vertical (3.3 V, IR_L, IR_R, GND), 2x M2. Refs 86xx.
    - kicad/hall-sensor: CC6201ST omnipolar Hall switch + 100 nF, SH 4-pin vertical, 2x M2;
    fitted twice (dust bin, LiDAR tower bumper). Refs 87xx.
    - main-phone SIDE-PROXI sheet: REAR-IR1 (PC8/PC9), HALL-BIN1 (PE4), HALL-TOWER1 (PE5),
    47k Hall pull-ups R7801/R7802; global labels to the MCU sheet; J7301 labels updated
    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
2026-10-30 LiDAR header, shunt, holes, Hall connector, INT pullup fix
2026-10-31 Per-board reference ranges, J1 spare header, IMU AD0 pull-down, BOM outputs
    - reference ranges: main-phone 1-999, dock 1000s, front ToF 2000s, side 3000s,
    cliff 4000s, rear IR 5000s, Hall 6000s (main-phone 7xxx parts renumbered
    below 1000; sensor boards and dock moved from 8xxx)
    - main-phone: J7301 -> J1, a fitted 2x7 0.1" header with spares only
    (3.3 V, 5 V, I2C4, UART PC10/PC11, PA8-PA10, PD4, PE2, PE6, GND)
    - IMU: AP_AD0 pulled low by R217 (address 0x68); INT2 on test pad TP1;
    FSYNC reachable on R211; R18/R72 removed
    - tools/export.py replaces export_pdfs.py: schematic PDF and JLC-style BOM in
    each board's output/ folder; --pcb adds Gerbers, placement and STEP
    - cliff and rear I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
2026-11-01 main-phone: power symbols, hierarchical signals; drop R19, LDR on VCC-3V3, J1 without I2C
    - fix: R19 pin 2 sat on the NRST wire, shorting the crystal output to reset
    - R19 (0R in series with the 8 MHz crystal) removed; PF1-OSC_OUT goes straight to X1
    - LDR (R75) runs from VCC-3V3 instead of the switched sensor rail
    - J1 pins 3/4 not connected (I2C4 kept off the header)
    - power global labels replaced with power symbols; PWR_FLAGs on the switched rails
    - rear IR, Hall, cliff LM/RM, DC_IN_SENSE, PWR-SW-G, WD_OK: hierarchical labels joined on the top sheet
    - visual tidy-up of the schematic sheets
    - docs and outputs regenerated
2026-11-01 main-phone: less busy schematic
    - GND symbol values hidden
    - pin numbers and names hidden on passives and diodes
    - visual tidy-up; netlist unchanged
2026-11-02 main-phone: single-FET sensor rail switch; rail and signal renames
    Sensor rail (VCC-3V3-REG) switch:
    - one AO3401 (Q16); Q17, R91, R96, R97 removed
    - D39 removed: it back-fed the "off" rail from the gate pull-up
    - R195 10k, R90 100k, C64 100 nF gate-drain (~2 ms soft start)
    - new C176 1 uF gate-source: keeps Q16 off while VCC-3V3 ramps up
    - 3.3V_EN drawn active low (~{3.3V_EN})
    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
2026-11-03 main-phone: battery voltage sense on PA8; analog bumpers
    - battery sense: R218 1M / R219 100k + C177 100 nF from P+/C+ (battery side
    of Q14, so it reads the battery while charging) to PA8 (ADC5_IN1), x11
    - J1 pin 7 (was PA8) not connected
    - bumper pull-ups R44/R48 47k -> 1k: the ITR9606 (IC(ON) 0.5-10 mA) no longer
    bottoms out, so PA4/PA5 (ADC2) see the slot opening and closing
    - docs: fix 2026-11-03 dates to 2026-11-02; visual tweaks; outputs updated
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2026-11-03 main-phone: motor enable on PA9, J1 spare on PE10; one pull-up
    - ~{VMOT-14V4-EN} moved from PE10 to PA9 (UCPD DBCC1): R184 (100k -> 10k)
    holds it high in reset, so the motors and LiDAR stay off and the CC1
    dead-battery Rd stays on
    - J1 pin 8 spare is PE10 now: no pull-up, ADC capable
    - R204 (old PA9 pull-up) and R182 (duplicate enable pull-up) removed
    - front sensors sheet: visual tweaks; docs and outputs updated
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2026-11-04 main-phone: drop MAIN_FAN2/3 and fan ID; LIDAR2 1x6 right angle (DNP)
    - MAIN_FAN2 (PA 5 / PH 5 / PH 4) and MAIN_FAN3 (PA 6) removed, with the
    fan ID circuit (R223, C180); other fans get an adapter cable
    - PE10 back on J1 pin 8 as SPARE-PE10
    - the two PA footprints and their 3D models removed from JLCImport
    LiDAR:
    - LIDAR2: 1x6 0.1" right-angle header PZ254R-11-06P (C492414), not fitted;
    pinout 1/2 VLIDAR-5V, 3 GND, 4 MOT-, 5 LiDAR TX, 6 LiDAR RX
    - renamed VM-5V-LIDAR -> VLIDAR-5V, LiDAR-M-CTRL -> LIDAR-MOTOR-CTRL
    - PWR_FLAG on the switched VLIDAR-5V rail
    Docs and outputs updated.
    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
2026-11-04 Cliff sensor renames; fix the middle cliff LED connection
    - main-phone: cliff nets LF-Q+ ... RM-Q+ renamed CLIFF-LF ... CLIFF-RM
    - fix: on the redrawn CLIFF sheet the CLIFF-LED-K wire crossed the
    CLIFF-LM1/RM1 pin 2 wire without a junction, leaving the middle cliff
    LEDs off Q35; wires split and junction added (connectivity as before)
    - cliff-sensor: VLED renamed VLED-5V; README pin 1 note updated
    - visual tweaks; outputs updated
2026-11-04 side-sensors: remove the XSHUT pull-up R3001
    - the MCU (PE3) drives XSHUT, and the sensor rail is off while the MCU is
    in reset, so the pull-up never sets XSHUT; firmware already has to hold
    PE3 low before the rail comes up (all ToF sensors start at 0x52)
    - board note updated: the main board holds the I2C and GPIO1 pull-ups
    - READMEs and outputs updated
2026-11-04 main-phone: remove R2, R62, R93, R215, R216; MCU drives or pulls instead
    - R2 (VL-I2C-RESET pull-down) and R62 (left ToF LPn pull-up): the MCU
    drives PC0/PB13, and the sensor rail is off whenever those pins float
    - R93 (IMU INT1 pull-up): firmware sets INT1 push-pull; R92 stays as the
    INT2 probe point
    - R215/R216 (Hall pull-ups): the MCU's internal pull-ups on PE4/PE5
    - VL-L-LPn renamed ~{VL-L-LPn}; LIDAR sheet filename case fixed
    - visual tweaks on the CLIFF, MAIN-FAN, WHEEL-MOTORs and STM32 sheets
    - SPEC, READMEs and outputs updated; cliff and wheel-drop pull-ups stay
2026-11-04 main-phone: remove the DRV8870 IN pull-downs
    - R3, R4 (main brush), R55, R57 (side brush), R11, R17, R20, R27
    (wheels): the DRV8870 has internal ~100k pull-downs on IN1/IN2, and
    the motor rail is off whenever the MCU pins float (reset, flashing)
    or the watchdog stops
    - off-grid wire cleanup on the motor sheets; leftover wires removed on
    the Front-Sensors, IMU and top sheets (no connectivity change)
    - SPEC, README and outputs updated
2026-11-04 main-phone: use KiCad's power:GND instead of the imported GND symbol
    - all 151 oomwoo-kicad-altium-import:GND_POWER_GROUND symbols replaced
    by power:GND (same pin position and orientation; netlist unchanged)
    - clears 152 "library not in the configuration" ERC warnings
    - Description field hidden on the GND symbols; wires merged on the motor
    sheets; outputs updated
2026-11-04 main-phone: clean up symbol library ERC warnings
    - resistor symbols updated from the library; C_0603 (missing library)
    replaced by Device:C
    - CL21A106KBYQNNE imported into JLCImport (pins passive); the 31 10 uF
    capacitors keep their own footprints, LCSC numbers and part numbers
    - R14, R89, R98, R90 moved from the DesignLibrary resistor to a
    JLCImport:R_US copy; rotation and text adjusted so pin numbering and
    the drawing match the previous version
    - JLCImport: C0603, C0805, R0603 footprints and 3D models (library
    defaults)
    - netlist unchanged; library warnings 117 -> 35, pin-type 274 -> 214
2026-11-05 libs: move shared libraries to kicad/libs; JLC footprints on main-phone
    - JLCImport and kicad/main/Libs moved to kicad/libs (git mv); every
    board's sym-lib-table / fp-lib-table points at ${KIPRJMOD}/../libs,
    kicad/main's tables included
    - 3D model paths in the moved footprints are ${KIPRJMOD}/../libs/...,
    so they resolve from any board folder (they only worked from
    kicad/main before); no absolute paths left
    - main-phone: Altium / vendor footprints replaced with JLC (EasyEDA)
    footprints, imported with easyeda2kicad: LEDs (YLED0603B), Q16/Q20
    (AO3401/AO3400), BUMP-L1/R1 (ITR9606-F), U13 (LQFP-100), U21/U22
    (SO-8 PowerPAD), D26-D28 (SOD-123; their symbol now numbers the
    cathode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
2026-11-05 main-phone: USB2 to HRO TYPE-C-31-M-12; MAIN_FAN1 on the Molex footprint
    - USB2: Korean Hroparts TYPE-C-31-M-12 (C165948, 154k in stock, 20 V
    5 A) replaces the GCT USB4215 (2 in stock), on its JLC symbol and
    footprint; every signal on the same function as before
    - MAIN_FAN1: JLC's Molex 43650-0400 footprint (C277684) for the Lian
    Xin XDWF (C50399536); JLC's own XDWF footprint numbers the pins
    mirrored against the datasheet and is not used. Fields describe the
    fitted Lian Xin part, Molex as the drop-in alternative
    - lib: JLC symbols for 43650-0400, TYPE-C-31-M-12 and XDWF (pointed at
    the Molex footprint); the 436500412 symbol BAT2 uses restored after
    the re-import overwrote it;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
2026-11-05 main-phone: PF0/PF1 on J1 as spares; MOSFET pins passive
    - SPARE-PF0 (ADC1_IN10) and SPARE-PF1 (ADC2_IN10) to J1 pins 5 and 7,
    free since the HSE crystal was removed
    - Q23, Q28, Q29, Q32, Q35, Q36 pins typed passive: pin-type ERC
    warnings 156 -> 117; netlist otherwise unchanged
    - tools/gen_pins.py: PF0-OSC_IN / PF1-OSC_OUT style pin functions count
    as GPIOs (they were silently skipped); PG10-NRST still excluded
    - SPEC J1 pinout and outputs updated
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2026-11-05 main-phone: R198 removed, R221 now a pull-up; front sensors on JLC parts
    - R198 (BUMP_L_LED_EN pull-down) removed: the bumper emitters run from
    VSENS-5V-USB, whose buck enable R168 holds low whenever the MCU pins
    float, so the LEDs cannot light in reset
    - R221 turned into a 100k pull-up to VMCU-3V3: PA10 is also UCPD DBCC2,
    so the dead-battery Rd is now on CC2 as well as CC1 in reset and the
    phone attaches in either plug orientation (was CC1 only)
    - BUMP-R-LED-K label flipped right of the drain wire to make room
    - front-sensors board: JLC symbols and footprints, LPn -> ~{LPn},
    PWR_FLAG on VAA-3V3 (ERC clean)
    - main-phone Front-Sensors sheet: JLC symbols and footprints
    - netlists ot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
2026-11-07 Front ToF boards plug straight into main-phone (2.0 mm 2x4 B2B)
    - VL-L1 / VL-R1: HanElectricity 2005FV-2x4P (C18723066) 2.0 mm 2x4
    vertical sockets, through hole, on the main board's underside
    - front-sensors J2001: 2005WR-2x4P (C6837622) right-angle header on the
    back of the ToF board; no cable
    - the mating swaps the rows, so header pin n meets socket pin n+1/n-1;
    both schematics are wired for it. Header: 1 3V3, 2 GND, 3 SDA, 4 SCL,
    5 INT, 6 I2C_RST, 7 ~LPn, 8 GND. The socket's odd row must face the
    ToF board (see the front-sensors README; 180 deg puts 3V3 on GND)
    - symbols, footprints and 3D models in kicad/lib (pins passive)
    - cliff pull-ups R39/R53/R64/R73/R212/R213 on JLCImpor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
2026-11-10 main-phone: DC1 back to the DC-044A-20A barrel jack
    5c7037a also switched DC1 to the 11 mm DC-005-5A-2_0, which its message
    did not mention. It came from Update Symbols from Library resetting DC1's
    fields to the defaults of the DC-005 symbol it was drawn with.
    - DC1 restored: DC-044A-20A (C129006), 7.2 mm, 30 V 5 A; same pin nets
    - new JLCImport:DC-044A-20A symbol (same pins and drawing as the
    DC-005), so a library update can't change the part again
    - netlist as before 5c7037a except R106; ERC unchanged
2026-11-10 charging-dock: J1001 on the DC-044A-20A symbol
    - J1001 was drawn with the DC-005-5A-2_0 symbol with DC-044A values
    typed over it, so a library update with field reset would have
    changed the part (as happened to the robot's DC1)
    - netlist, value, LCSC number and footprint unchanged
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2026-11-11 LIDAR2: 2x3 right-angle header instead of 1x6
    LIDAR2 (not fitted) is now the XFCN PZ254R-12-06P-A40 (C45384673), the 2x3
    version of J1's header: 7.6 mm of board edge instead of 15.2 mm. Same symbol,
    pin numbers and nets (odd pins in one row, even in the other); JLC footprint
    and 3D model added to kicad/lib. Top-sheet sheet names for Bumper Sensors and
    USB Power hidden. Docs and outputs updated.
2026-11-12 main-phone: fix reversed D37/D11, one SS34 part, library field fixes
    - D37 (VMOT-14V4 clamp) and D11 (LiDAR motor flyback) were reversed on the
    PCB: their old imported symbol numbered the anode pin 1, but pad 1 of the
    SMA footprint is the cathode. Both now use the JLC SS34 symbol and
    footprint (MDD SS34, C8678, Basic) like D4: one BOM line instead of two
    - TPS54560BDDAR library symbol carried the AP64501's LCSC number and
    manufacturer; U21/U22 back to C1850354 / Texas Instruments
    - XRNR4030 10 uH inductor library prefix U -> L; U4 back to L4
    - schematic cleanup: values tidied, passives on JLC footprints, D46 -> LED1
    - README, outputs updated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
2026-11-12 main-phone: C102 back on VBAT, stale ERC exclusion removed, cleanup
    - C102's top wire had ended on U21's EN wire (with a junction) after the
    switch to the JLC capacitor symbol; it joins VBAT-14V4 again, as in HEAD
    - removed the "pin not driven" ERC exclusion left over from the Pi board
    (its item no longer exists here); ERC is clean
    - PowerPAD footprint 3D path relative again (KiCad had saved it absolute)
    - D44, D45 renamed LED2, LED3; U21/U22 on JLC's SO-8 PowerPAD footprint;
    more caps on JLC footprints; README and outputs updated
2026-11-13 main-phone: latch hold-off cap C2, J3 fitted, renames and JLC parts
    - C2 (10 uF) from PWR-LATCH (Q23 gate) to GND: R172 holds the latch in
    hardware, so after a firmware power-off the decaying rail could pull Q23
    back on once the MCU releases PA15; C2 keeps the gate low until the rail
    is gone (10k x 10 uF = 100 ms). Blank-MCU turn-on still fits in the
    ~0.25 s button pulse
    - SPEC: latch description corrected (hardware holds it, firmware only turns
    off); C2 timing and the bring-up checks
    - LIDAR2 renamed J3 (JLC PZ254R-12-06P-A40 symbol) and now fitted
    - renamed POWER-EN -> VMCU-3V3-POWER-EN, VSENS_5V_USB_EN -> VSENS-5V-USB-EN,
    IMU-AD0/FSYNC/INT2 -> AD0/FSYNC/INT2; more passives on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

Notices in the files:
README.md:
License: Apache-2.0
